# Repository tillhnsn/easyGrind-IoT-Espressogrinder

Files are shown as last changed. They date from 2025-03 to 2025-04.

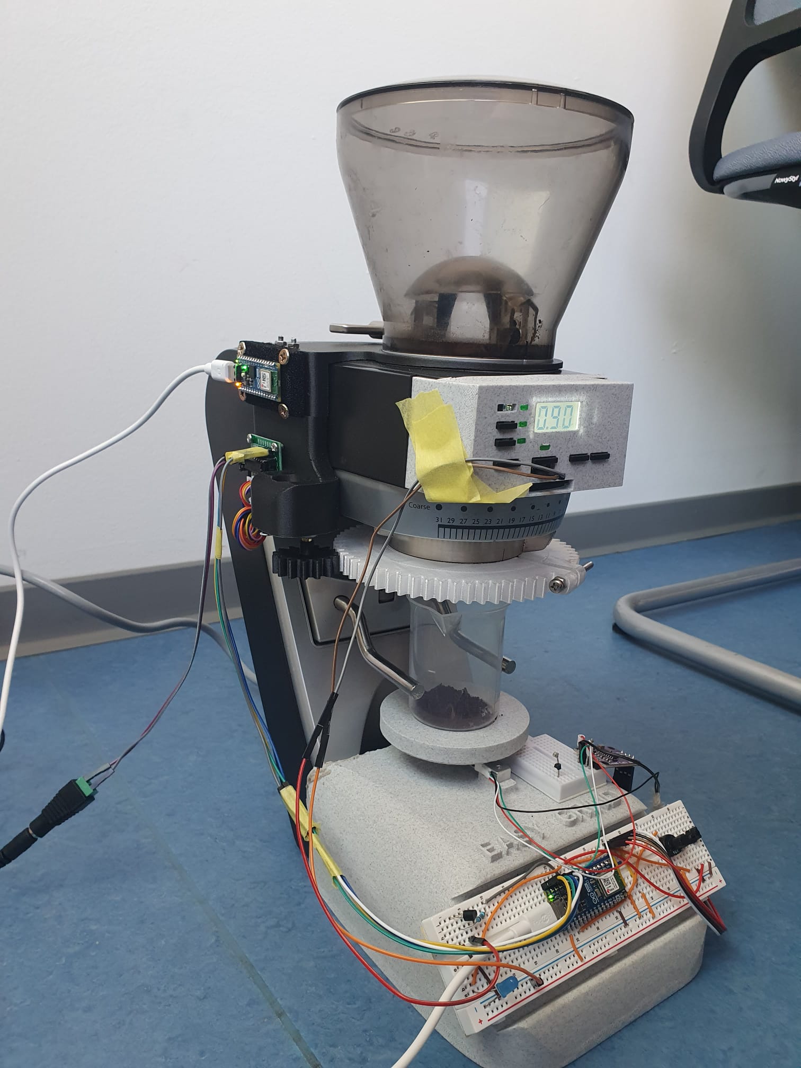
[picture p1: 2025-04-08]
pictures/easyGrind_komplett.jpg

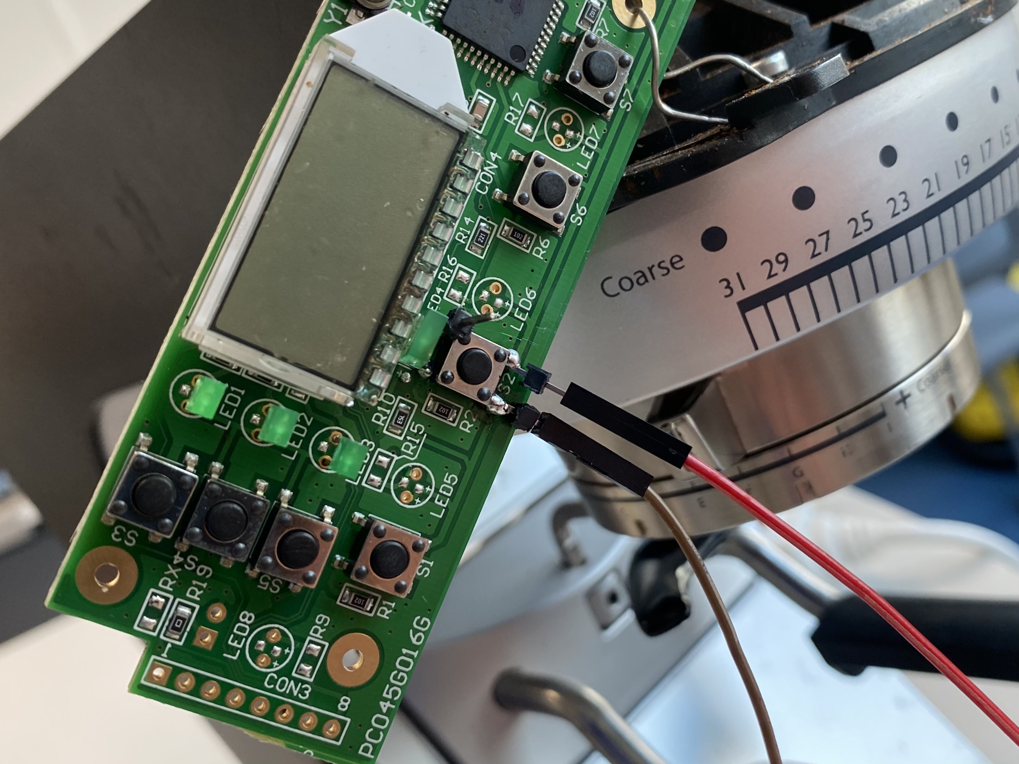
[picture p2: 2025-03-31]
pictures/Taster Überbrückung.jpg

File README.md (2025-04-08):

# ESP32 Grinder Controller – Grind Size & Grind-by-Weight

## Project Overview
An ESP32-powered controller for automatic control of grind size and grind-by-weight in an espresso grinder.  
To avoid working with high voltage, the GBW (Grind-by-Weight) control bypasses the grinder’s start/stop button on the control panel.  
This makes the code compatible with nearly any grinder that uses a physical button for start/stop.  
The STL models for grind size adjustment need to be adapted depending on the grinder model. In this example (Baratza Sette 270), it is implemented via a clamped gear (see images).

## Features
- **Web interface** for control and configuration  
- **Grind-by-Weight**  
- **Automatic grind size adjustment** using a stepper motor  
- **Start/Stop and Tare function** via physical button or web interface  

## Required Components
### **Electronic Components**
- 1x **Arduino Nano / ESP32** microcontroller  
- 1x **HX711** load cell amplifier  
- 1x **Load cell** (up to 750g capacity)  
- 1x **Stepper motor** (e.g. 28BYJ-48)  
- 1x **ULN2003 driver board**  
- 1x **NPN transistor** (e.g. BC547)  
- 1x **Potentiometer** (10 kΩ)  
- 2x **Push buttons** (Start/Stop & Tare)  
- 1x **LED** (optional)  
- Jumper wires, connectors, breadboard  

### **Tools**
- Soldering iron and solder  
- Screwdriver  
- Multimeter for voltage testing  
- 3D-printed mounts and parts  

## Bypassing the Start/Stop Button
1. Remove the grinder control housing  
2. Measure continuity of the button using a multimeter  
3. Solder new pins onto the button’s solder joints  
4. Connect the button to the transistor collector and GND using jumper wires  

## Wiring
### **ESP32 Pin Mapping**
| Component | ESP32 Pin | Notes |
|---|---|---|
| **HX711 DT** | `D2` | Data pin from load cell |
| **HX711 SCK** | `D3` | Clock pin from load cell |
| **LED (Status)** | `D7` | Indicates active grinding process |
| **Motor Control (NPN)** | `D8` | Used to turn motor on/off |
| **Potentiometer** | `A0` | Analog input for target weight |
| **Start Button** | `D6` | Start/Stop function |
| **Tare Button** | `D5` | Tares the scale |
| **Stepper Motor IN1** | `D9` | Control signal 1 |
| **Stepper Motor IN2** | `D10` | Control signal 2 |
| **Stepper Motor IN3** | `D11` | Control signal 3 |
| **Stepper Motor IN4** | `D12` | Control signal 4 |

### Transistor Configuration
| NPN Pin | Connection |
|---|---|
| **Collector** | To grinder's bypassed start button |
| **Emitter** | GND |
| **Base** | Via resistor (1kΩ) to `D8` |

## Software Installation
1. **Install Arduino IDE**  
2. **Add Arduino Nano ESP32 Board**  
   - **Tools → Board → Board Manager**  
3. **Install required libraries**  
4. **Connect ESP to your Wi-Fi in the code** (change SSID and password)  
5. **Upload the code**  
   - Load source code from `Arduino Code` into the Arduino IDE  
   - Select the correct port under **Tools → Port**  
   - Start upload  

## Setup & Calibration
1. **Start the ESP32**  
2. **Connect via web interface** (e.g. `http://192.168.4.1`)  
   - The exact IP address is shown in the Arduino IDE Serial Monitor  
3. **Calibrate the scale**: press "Tare" and place a calibration weight  
   - Adjust calibration value using known weight  
   - Set value in the code under `HX711 initialization`  
   - `newValue = oldValue * (measured weight / target weight)`  
4. **Test run**: Set target weight and start grinding
5. start with offset = 0g and adjust if needed

## Grind Size Adjustment
1. If necessary, redesign 3D parts to fit your grinder  
2. **WARNING**: No endstops present → Before each use, manually set both the grinder and web interface to the finest grind setting to avoid collisions  
3. Depending on your grinder, adjust the step size in the code to get meaningful grind adjustments  

## ⚠️ Safety Notes
- Stepper motor and driver can overheat quickly  
- Isolate all open contacts to prevent short circuits  

## License
This project is licensed under the **MIT License** and may be freely used, modified, and shared.

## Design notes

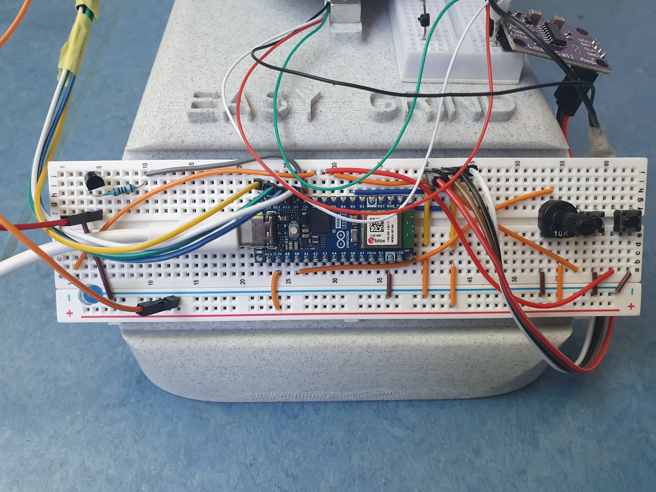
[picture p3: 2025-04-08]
pictures/easyGrind_verschaltung.jpg

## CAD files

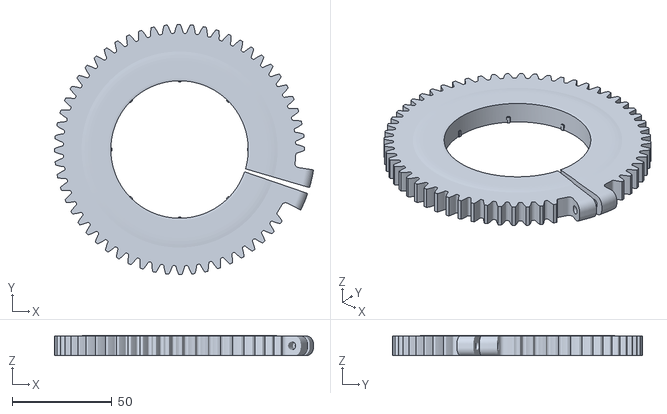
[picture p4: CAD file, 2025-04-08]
3dModels/Zahnrad_gross.stl
130.0 x 125.5 x 10.3

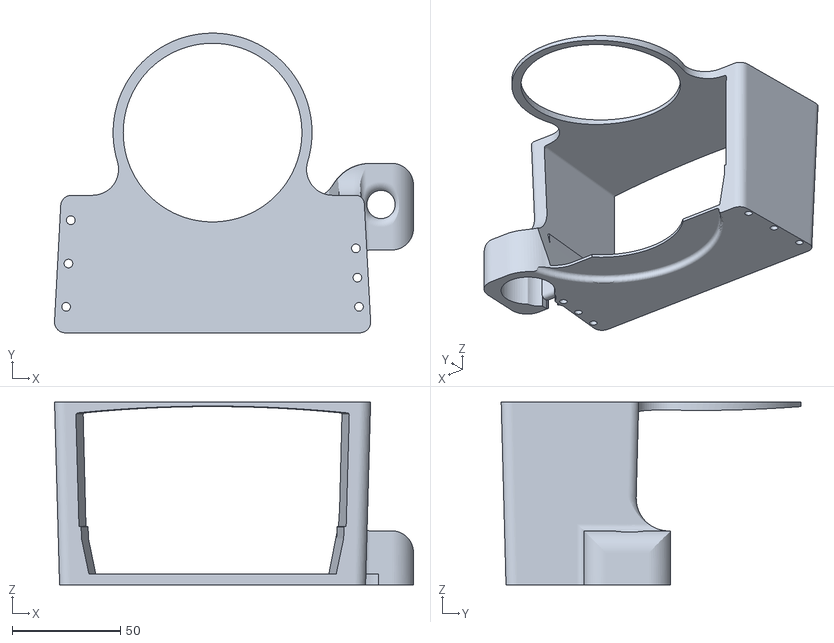
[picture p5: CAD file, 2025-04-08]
3dModels/Motor_Halter.stl
165.8 x 138.4 x 84.5

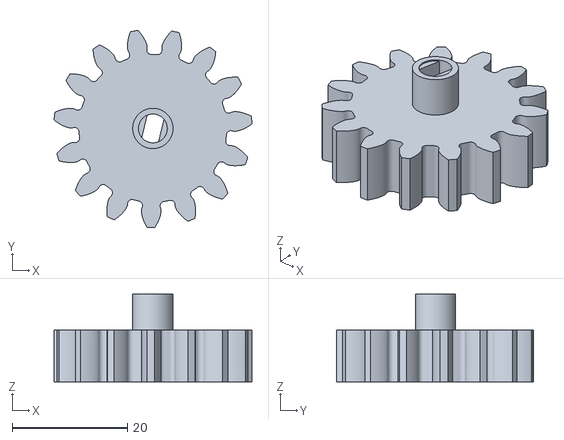
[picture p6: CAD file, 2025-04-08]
3dModels/Zahnrad_klein.stl
34.3 x 34.2 x 15.2

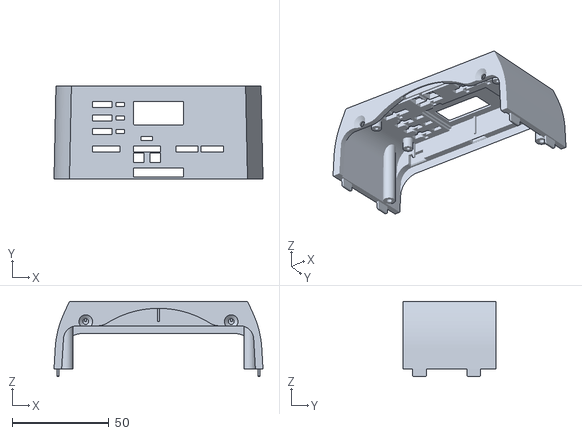
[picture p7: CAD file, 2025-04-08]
3dModels/Vorderblende.stl
108.0 x 48.0 x 39.0

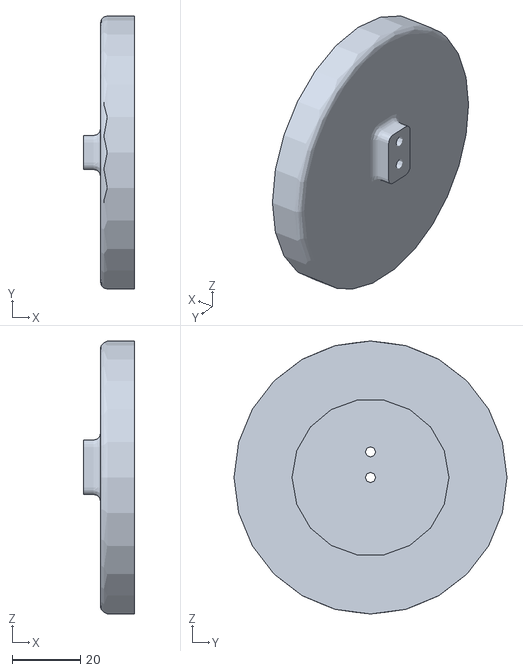
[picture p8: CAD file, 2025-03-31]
3dModels/Waage-Platte.stl
15.0 x 80.0 x 80.0

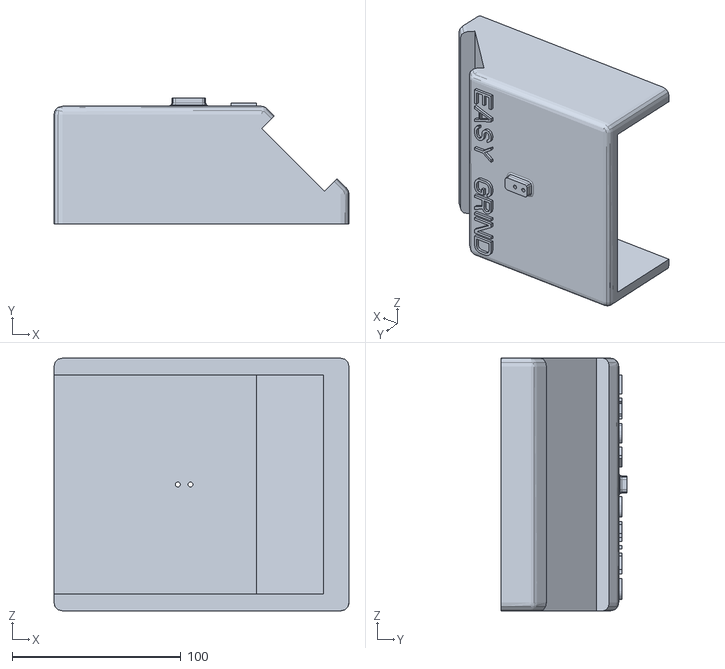
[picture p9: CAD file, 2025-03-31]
3dModels/GBW-Tisch.stl
175.0 x 75.0 x 150.0

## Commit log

2025-03-31 Create Arduino Code
2025-04-08 Update Arduino Code
